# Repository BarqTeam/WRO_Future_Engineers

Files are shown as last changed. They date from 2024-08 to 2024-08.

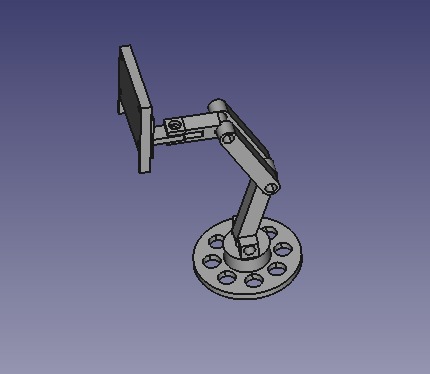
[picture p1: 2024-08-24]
models/camerastand/assembly_for_the_stand.jpeg

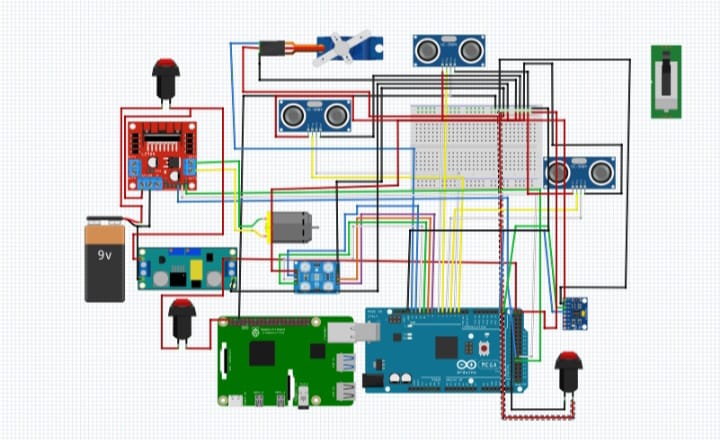
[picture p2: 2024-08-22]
schemes/Schematic_diagram.jpeg

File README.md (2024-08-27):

Engineering materials
====

This repository contains engineering materials of a self-driven vehicle's model participating in the WRO Future Engineers competition in the season 2022.

## Content

* `t-photos` contains 2 photos of the team (an official one and one funny photo with all team members)
* `v-photos` contains 6 photos of the vehicle (from every side, from top and bottom)
* `video` contains the video.md file with the link to a video where driving demonstration exists
* `schemes` contains one or several schematic diagrams in form of JPEG, PNG or PDF of the electromechanical components illustrating all the elements (electronic components and motors) used in the vehicle and how they connect to each other.
* `src` contains code of control software for all components which were programmed to participate in the competition
* `models` is for the files for models used by 3D printers, laser cutting machines and CNC machines to produce the vehicle elements. If there is nothing to add to this location, the directory can be removed.
* `other` is for other files which can be used to understand how to prepare the vehicle for the competition. It may include documentation how to connect to a SBC/SBM and upload files there, datasets, hardware specifications, communication protocols descriptions etc. If there is nothing to add to this location, the directory can be removed.

  ## READ.ME table of content

1. [Project Overview](#project-overview)

   1.1. [Team Management](#Team-Management)
   
   1.3. [Vehicle Strengths](#Vehicle-Strengths)  

2. [Programming Language ](programming-language)

3. [The First Chassis](#The-First-Chassis)

4. [Programming Challenges](#Programming-Challenges)

5. [Lap Counting Mechanism](#Lap-Counting-Mechanism)

6. [Obstacle Avoidance Round Challenge](#Obstacle-Avoidance-Round-Challenge)

7. [Power](#Power)

8. [components](#components)

9. [Future Work](#Future-Work)

## Introduction

Hello everyone,

We are the [Barq Engineers] from Palestine. We are a group of three ambitious young men: Amjad Ghannam, Rayan Farid, and Qusay Laila , with our car {BURAQ} represents not only our drive for technological advancement but also a symbol of hope and aspiration for the people of Palestine. Burag reflects the speed and brilliance of this legendary creature, embodying our ambition to overcome obstacles and make a mark on the world stage. Through Burag, we aim to demonstrate the remarkable achievements that Palestinian youth can accomplish, even in the face of adversity. .

In this competition, our goal is to showcase to the world what Palestinian youth can achieve, even under the harsh conditions of occupation. Through our efforts, we aim to send a powerful message about resilience, creativity, and the limitless potential that exists within every Palestinian boy.

## Project Overview

We began working on the WRO Future Engineers 2024 competition nearly three months ago. 
The WRO Future Engineers competition challenges teams to design and build autonomous vehicles capable of navigating complex paths and obstacles. Participants must integrate advanced engineering, programming, and design skills to create innovative solutions. The competition emphasizes creativity, technical precision, and teamwork, pushing the limits of robotics and AI. Teams showcase their work in a final competition, judged on performance, design, and innovation.

Our team, led by Qusay Laila, developed an advanced self-driving car from scratch, integrating CNC-machined and 3D-printed parts with components from the EV3 Lego kit. Powered by a 24-volt lithium battery, the car boasts high speed, smooth maneuverability, and excellent acceleration thanks to a well-designed differential and a gear ratio of 1.4:1. We included a Pi camera for obstacle detection and fine-tuned its software for optimal performance. We ensured the vehicle's seamless integration of mechanical and software systems. The car is lightweight at 1.2 kg, with room to compete in various challenges beyond the Future Engineers competition. Our GitHub repository documents the entire journey, including coding, design, and team management strategies.
You can find more details about the competition in the official rules.

## 1.1 Team Management

We are deeply grateful to everyone who contributed to our work. The success of this project is a testament to the dedication and collaboration of our incredible team, which consists of:

* Amjad Ghannam:
Amjad is responsible for managing our social media accounts, including GitHub. He is the creative force behind our design concepts, overseeing the development of the car's body, its mechanical systems, and other related components. Additionally, Amjad assists with coding.
`Contact Information:`
                    _ Email: amjadgh72@gmail.com
                    _ WhatsApp: +972594387565

* Qusay Laila:
Qusay is our team leader and the mastermind behind problem-solving. He excels in CAD design and manages the main code, assembling all the functions like pieces of a Lego set.
`Contact Information:`
                   _ Email: qusaylaila.work@gmail.com
                    _WhatsApp: +972592509054

* Rayan Farid:
Rayan is our designer for 3D parts and CNC components. He also manages serial communication and contributes to the code alongside Qusay. Additionally, Rayan serves as a GitHub editor.
`Contact Information:`
                    _ Email: rayanplaystation180@gmail.com
                     _WhatsApp: +972568997345

*The Coach: Eng. Mohammad Muamar
Eng. Mohammad Muamar, a Palestinian engineer and graduate of Palestine Polytechnic University in Hebron, has been our steadfast guide throughout this journey. His unwavering support, especially during challenging times, has been invaluable.
`Contact Information:`
Email: moh.mummar@gmail.com
Phone: +970594958003
Palestine Polytechnic University

We extend our heartfelt gratitude to our coach and all the team members who have played a crucial role in bringing this project to life.

## 1.2Barq team's social accounts
* youtube : https://www.youtube.com/@barqteam
* Instagram : https://www.youtube.com/redirect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
* you can also check our personal accounts in 1.1. [Team Management](#Team-Management)

## 1.3Vehicle Strengths
*  Chassis and Mechanism : Our vehicle was meticulously built from scratch, utilizing CNC-machined and 3D-printed parts. We also incorporated components from the EV3 Lego kit for critical mechanisms, such as the steering system and differential.

* Speed: Powered by a 24-volt lithium battery, our car achieves impressive speeds, giving it a competitive edge in performance.

* Mobility and Flexibility: The differential system significantly enhances the vehicle's ability to maneuver, providing smooth and flexible turns.

* Acceleration: The car boasts excellent acceleration, thanks to a well-calibrated gear ratio of 1.4:1 and a high-torque gear system that delivers powerful performance.

 ## 2. Programming Languages
We utilized C++ for coding the Arduino, ensuring efficient and reliable control of the hardware. Additionally, we employed Python to code the Raspberry Pi, particularly for implementing OpenCV with the Pi Camera.

## 3. The First Chassis
Initially, we decided to modify an RC car by adding the necessary components and creating a second layer to put them on. However, we encountered several challenges. The first issue arose when trying to create proper holes for mounting the servo motor. This led to further complications when attempting to implement a rack and pinion steering system (you can view the FreeCAD models for the rack and pinion in the "Models" section of this repository) using an MG699R servo motor.

Due to the high power and torque of the servo, it couldn't stay securely in place and kept shifting, which compromised the stability of the steering system. As a result, we decided to move on to our next plan: building a new chassis from scratch.

## 4. Programming Challenges
##Detecting Turns and Direction
In the WRO Future Engineers competition, the car's direction isn't fixed—it can move either clockwise or counterclockwise, adding complexity to navigation. This unpredictability is particularly challenging when the car needs to execute precise U-turns at specific points on the track.

### First Solution: Using the TCS3200 Color Sensor
* Color Detection: We initially programmed the TCS3200 sensor to identify specific colors on the track. An orange line signaled that the car should turn clockwise, while a blue line indicated a counterclockwise turn.

* Controlled Turning: Upon detecting a color, the car was instructed to turn at a specific angle. This angle was precisely controlled using an Inertial Measurement Unit (IMU), ensuring the car made accurate and consistent turns, regardless of external factors like speed or track conditions.

* Code Implementation: The process was automated through predefined functions such as detectOrangeLine and detectBlueLine, which triggered the appropriate turning actions based on the color detected.

This approach provided a straightforward method for determining the car's direction based on visual cues from the track, with the IMU ensuring precise turning control. However, this solution proved suboptimal due to the car's high speed and the limitations of the TCS3200, which was not the best choice for color detection in this context.

### Second Solution: Using Three Ultrasonic Sensors
* Direction Determination: We implemented three ultrasonic sensors to guide the car's movement based on real-time distance measurements. These sensors were strategically positioned to monitor distances on the left, right, and front of the car. When a turn was required, the direction was determined by comparing the distances detected by the sensors:

* If the right sensor measured a greater distance than the left sensor, the car would turn clockwise.
* Conversely, if the left sensor detected a greater distance, the car would turn counterclockwise.
#### Front Sensor Activation:
The front ultrasonic sensor played a critical role in detecting when the car was approximately 50 cm away from an obstacle or a turning point. This detection served as a trigger for the car to initiate the turn.

This approach emphasized spatial awareness and precise distance measurement, allowing the car to make informed directional decisions based on its environment rather than relying on visual cues. Ultimately, we decided that this solution was the most effective for our needs.

## 5.Lap Counting Mechanism:
#### Loop-Based Counting with Ultrasonic Sensor and IMU

##### Overview:
This method utilizes a software-based loop counter to track lap completion. The robot employs an ultrasonic sensor to detect when a lap is completed. If the sensor measures a distance of less than 50 cm to a specified point or object, the system registers the start of a new lap. The robot's steering is precisely managed by an Inertial Measurement Unit (IMU), ensuring accurate navigation during turns.

## IMU-Based Steering
#### Overview: 
In our autonomous vehicle, precise steering control is essential for accurate navigation. We achieve this through an IMU-based steering mechanism. The Inertial Measurement Unit (IMU) supplies real-time data on the vehicle’s angular velocity, which is crucial for calculating the yaw angle (the vehicle's turning angle) and ensuring stable and accurate steering.

#### Understanding the IMU:
An IMU (Inertial Measurement Unit) integrates several sensors, typically including a 3-axis accelerometer and a 3-axis gyroscope. These components work together to monitor the vehicle's movement and orientation in three-dimensional space.

* Accelerometer: Measures acceleration along the X, Y, and Z axes, which helps determine the vehicle’s tilt and linear movement.
* Gyroscope: Measures angular velocity (the rate of rotation) around the X, Y, and Z axes, providing critical information for understanding rotational motion, especially the yaw angle.
#### The X, Y, and Z Axes: 
Understanding these axes is fundamental for interpreting IMU data:

* X-Axis: Represents roll, the tilting motion of the vehicle from side to side.
* Y-Axis: Represents pitch, the tilting motion of the vehicle from front to back.
* Z-Axis: Represents yaw, the rotational movement around the vertical axis, crucial for steering as it defines the vehicle’s direction of travel.
#### Calculating the Yaw Angle: 
The yaw angle (
�
�
θ 
z

 ) quantifies the vehicle's rotation around the Z-axis. The IMU’s gyroscope provides angular velocity data along this axis, indicating the rate of rotation.

To determine the vehicle's heading, we calculate the yaw angle by integrating the angular velocity over time. This calculation updates continuously to maintain precise tracking of the vehicle’s direction.

The yaw angle is computed using the following equation:

\theta_z = \theta_{z, \text{previous}} + \left( \frac{\text{gyro}_z - \text{gyro_z_offset}}{131.0} \right) \times \Delta t

Where:

�
�
θ 
z

  is the current yaw angle.
�
�
,
previous
θ 
z,previous

  is the yaw angle from the previous time step.
gyro
�
gyro 
z

  is the angular velocity around the Z-axis, provided by the gyroscope.
\text{gyro_z_offset} is the gyroscope offset, determined during calibration to correct for any drift.
Δ
�
Δt is the time elapsed between the current and previous readings.
### Importance of Gyro Offset:
The gyroscope offset (\text{gyro_z_offset}) is vital as gyroscopes can experience slight errors or biases over time, known as drift. By calculating and subtracting this offset, we ensure that the yaw angle calculation remains accurate, preventing gradual deviations from the true value.

## 6. Obstacle Avoidance Round Challenge
In this round, we integrated the Pi camera to enable the car to navigate between obstacles more efficiently. We started by developing the optimal code to achieve the best resolution and frame rate, while also fine-tuning color filters to ensure precise detection of red and green obstacles. This setup allows the car to identify and respond to obstacles accurately, minimizing the risk of errors. 
Here, you can see the code we developed to optimize the color filters, ensuring the highest accuracy in obstacle detection. This code is tailored to deliver the best possible resolution and frame rate, allowing our car to efficiently identify and respond to red and green obstacles with minimal errors.

cpp
import picamera
import cv2
import numpy as np
import serial
from picamera.array import PiRGBArray
import time

#Initialize serial communication with Arduino
arduino = serial.Serial('/dev/ttyACM0', 115200)  # Replace with your actual port

#Initialize Picamera
camera = picamera.PiCamera()
camera.resolution = (500, 200)  # Lower the resolution for faster processing
camera.framerate = 60  # Increase the frame rate
camera.brightness = 50  # Increase brightness by approximately 50%
raw_capture = PiRGBArray(camera, size=(500, 200))

#Allow the camera to warm up
time.sleep(0.1)

def format_data(object_type, x, y, width, height):
    """Format data as a string."""
    return f"{object_type}{x:05}{y:05}{width:05}{height:05}\n"

def get_largest_contour(mask, min_area=500):
    """Find the largest contour in the given mask, ignoring small contours."""
    contours, _ = cv2.findContours(mask, cv2.RETR_TREE, cv2.CHAIN_APPROX_SIMPLE)
    filtered_contours = [c for c in contours if cv2.contourArea(c) > min_area]
    if filtered_contours:
        largest_contour = max(filtered_contours, key=cv2.contourArea)
        return largest_contour
    return None

try:
    for frame in camera.capture_continuous(raw_capture, format="bgr", use_video_port=True):
        imageFrame = frame.array

        # Increase contrast
        contrast_factor = 1.5  # Adjust this value to increase contrast
        imageFrame = cv2.convertScaleAbs(imageFrame, alpha=contrast_factor, beta=0)

        # Convert BGR image to HSV
        hsvFrame = cv2.cvtColor(imageFrame, cv2.COLOR_BGR2HSV)

        # Increase saturation and brightness to make colors more vivid
        hsvFrame[:, :, 1] = cv2.add(hsvFrame[:, :, 1], 30)
        hsvFrame[:, :, 2] = cv2.add(hsvFrame[:, :, 2], 30)

        # Define color ranges
        red_lower1 = np.array([0, 140, 140], np.uint8)
        red_upper1 = np.array([10, 255, 255], np.uint8)
        red_lower2 = np.array([160, 140, 140], np.uint8)
        red_upper2 = np.array([180, 255, 255], np.uint8)

        green_lower = np.array([35, 100, 100], np.uint8)
        green_upper = np.array([85, 255, 255], np.uint8)

        # Create masks for red and green colors
        red_mask1 = cv2.inRange(hsvFrame, red_lower1, red_upper1)
        red_mask2 = cv2.inRange(hsvFrame, red_lower2, red_upper2)
        red_mask = cv2.bitwise_or(red_mask1, red_mask2)

        green_mask = cv2.inRange(hsvFrame, green_lower, green_upper)

        # Apply additional thresholding to refine masks
        kernel = np.ones((7, 7), "uint8")  # Slightly larger kernel size
        red_mask = cv2.dilate(red_mask, kernel)
        red_mask = cv2.erode(red_mask, kernel)

        green_mask = cv2.dilate(green_mask, kernel)
        green_mask = cv2.erode(green_mask, kernel)

        # Find the largest red and green objects
        largest_red_contour = get_largest_contour(red_mask)
        largest_green_contour = get_largest_contour(green_mask)

        # Process the largest red object
        if largest_red_contour is not None:
            rect = cv2.minAreaRect(largest_red_contour)
            box = cv2.boxPoints(rect)
            box = np.int0(box)
            imageFrame = cv2.drawContours(imageFrame, [box], 0, (0, 0, 255), 2)
            
            width = int(abs(rect[1][0]))
            height = int(abs(rect[1][1]))
            
            # Calculate the center X position
            x_center = int((box[0][0] + box[2][0]) / 2)
            y_center = int(rect[0][1])
            
            data_red = format_data(1, x_center, y_center, width, height)
            arduino.write(data_red.encode())
            print(data_red)
        # Process the largest green object
        if largest_green_contour is not None:
            rect = cv2.minAreaRect(largest_green_contour)
            box = cv2.boxPoints(rect)
            box = np.int0(box)
            imageFrame = cv2.drawContours(imageFrame, [box], 0, (0, 255, 0), 2)
            
            width = int(abs(rect[1][0]))
            height = int(abs(rect[1][1]))
            
            # Calculate the center X position
            x_center = int((box[0][0] + box[2][0]) / 2)
            y_center = int(rect[0][1])
            
            data_green = format_data(2, x_center, y_center, width, height)
            arduino.write(data_green.encode())
            print("green")
            print(data_green)
        # Display the result
        cv2.imshow("colors", imageFrame)
        
        # Clear the stream for the next frame
        raw_capture.truncate(0)

        # Add a delay and check for 'q' key press
        if cv2.waitKey(1) & 0xFF == ord('q'):
            break

finally:
    # Close serial connection and camera when done
    arduino.close()
    camera.close()
    cv2.destroyAllWindows()

## 7.Power 
Lithium Polymer (LiPo) batteries are highly favored in robotics due to their superior energy density, lightweight construction, and capability to deliver high currents. These attributes make them exceptionally suited for applications that demand both substantial power and agility, such as our autonomous robot.
Advantages of LiPo Batteries:

1- High Energy Density:

2- High Discharge Rate:

3- Lightweight and Compact:

4- Stable Voltage Output:

### Why a 24V Battery?
#### Voltage Compatibility:

The 24V output is ideal for many high-power robotics components, such as motors and motor drivers, which are designed to operate efficiently at this higher voltage. This reduces the need for additional voltage conversion and simplifies the power distribution system, making it more efficient for demanding applications.

#### Power Sufficiency:

A 24V battery provides ample power for the entire robot, ensuring that high-demand components like motors receive sufficient voltage for optimal performance. This higher voltage allows for efficient voltage regulation to lower voltages (e.g., 5V or 3.3V) for other electronics, while maintaining overall power efficiency.

Key Characteristics of the 24V LiPo Battery:

* Voltage: 24V nominal, ideal for direct use with high-power motors and for stepping down to lower voltages.
* Capacity: Typically ranges from 2000mAh to 6000mAh, influencing how long the robot can operate before requiring a recharge.
* Discharge Rate: High C-ratings (e.g., 20C) ensure the battery can deliver the necessary current for motors and other components during peak usage.
* Weight: Lightweight design, generally around 300g for a 2200mAh battery, important for maintaining the robot’s agility and maneuverability.

  ## 8.components
| Quantity | Status | Description |
| ---| --- | ---|
| 1 | Raspberry Pi 4 Model B |https://www.raspberrypi.com/products/raspberry-pi-4-model-b/ |
| 1 | *Arduino Mega: | (https://store.arduino.cc/products/arduino-mega-2560-rev3) |
| 1 | The L298N Motor Driver: | https://components101.com/modules/l293n-motor-driver-module |
| 1 | Servo motor MG996r |https://www.jsumo.com/mg996r-servo-motor-digital |
| 1 | pi camera module 2| https://www.raspberrypi.com/products/camera-module-v2/ |
| 1 | MPU-9250 |https://learn.sparkfun.com/tutorials/mpu-9250-hookup-guide/all |
| 3 | *HC-SR04 Ultrasonic Sensor  | https://www.sparkfun.com/products/15569 |
|1 | lithum Battery 24v | "We have connected two 12-volt batteries in series using a 6S Battery Management System (BMS) to ensure balanced charging and efficient power management." |
|1 | HW-083 | https://www.elektormagazine.com/labs/hw-083-hack-evolution-charger |

## 9.Future Work
Our car is versatile enough to compete in multiple competitions beyond the Future Engineers competition. Its high speed, lightweight design, and exceptional flexibility in turning—thanks to the differential gear system—make it a strong contender. Additionally, the precise steering system enhances its maneuverability, allowing it to perform with accuracy and agility across various challenges.

## How to prepare the repo based on the template

_Remove this section before the first commit to the repository_

1. Clone this repo by using the `git clone` functionality.
2. Remove `.git` directory
3. [Initialize a new public repository on GitHub](https://github.com/new) by following instructions from "create a new repository on the command line" section (appeared after pressing "Create repository" button).

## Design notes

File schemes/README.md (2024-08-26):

Electromechanical diagrams
====
This section details all the components utilized in the project, accompanied by a schematic diagram illustrating how they are interconnected.

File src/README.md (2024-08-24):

Control software
====

In this repository, we have uploaded various code versions that document each stage of our development process. Each file is named for easy reference, allowing you to efficiently track progress and identify the final, most optimized version.

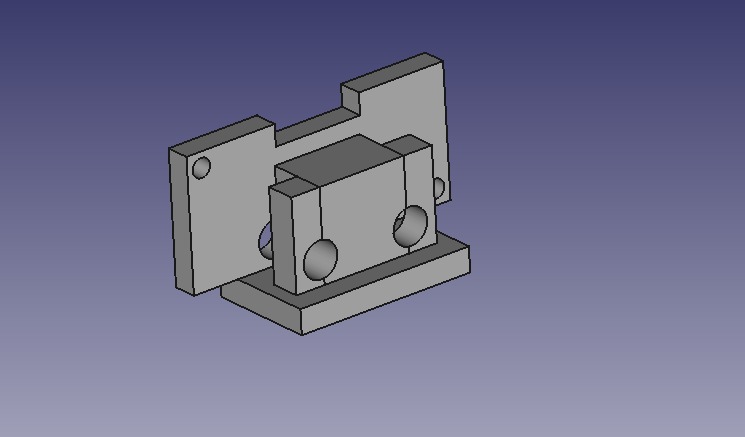
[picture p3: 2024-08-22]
models/ultrasonic_right+left.jpeg

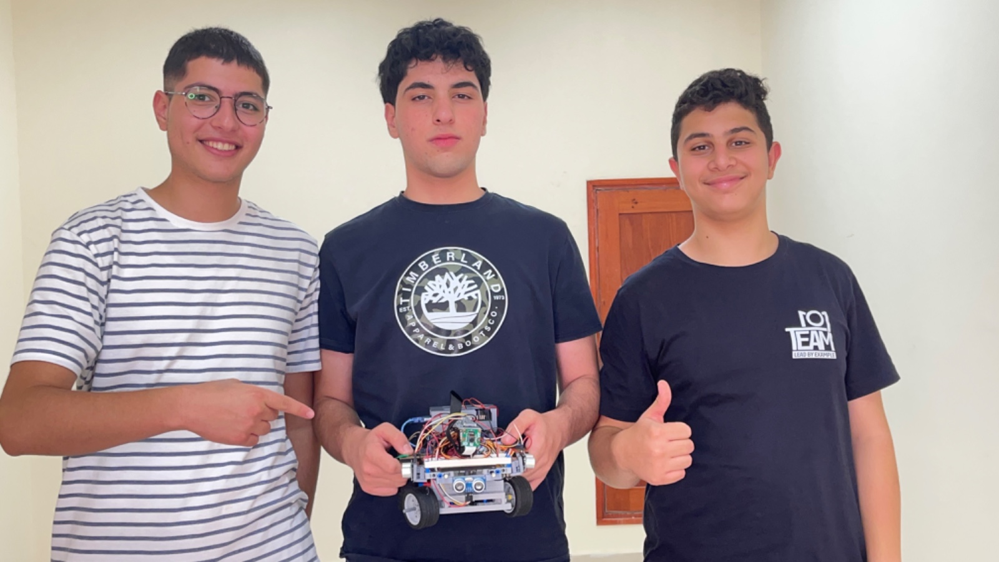
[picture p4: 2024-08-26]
t-photos/teamphotowithcar.jpeg

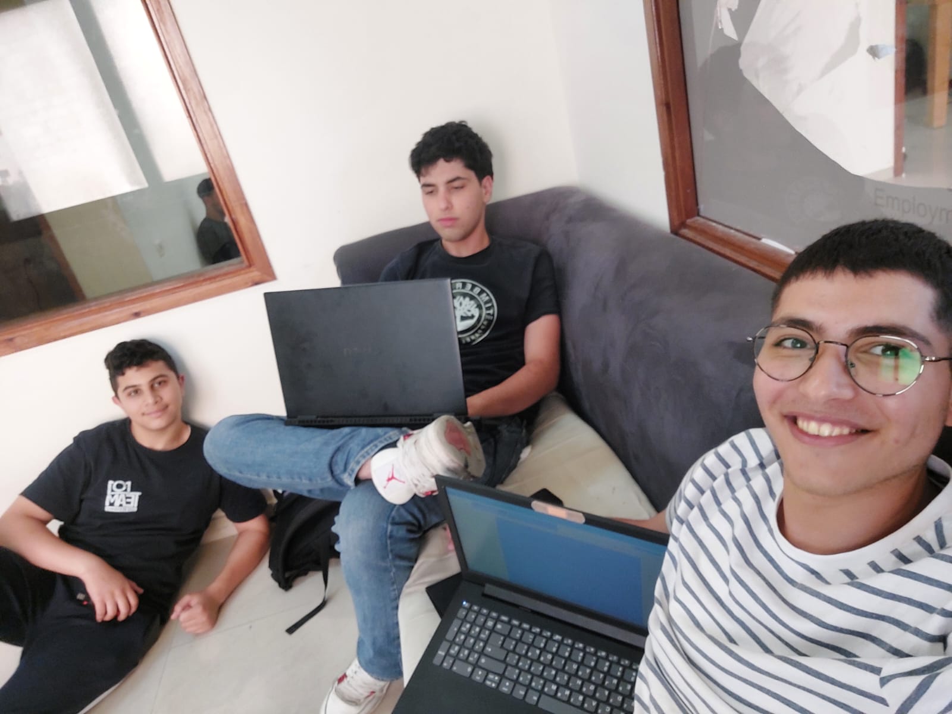
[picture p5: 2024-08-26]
t-photos/Funnyphoto.jpeg

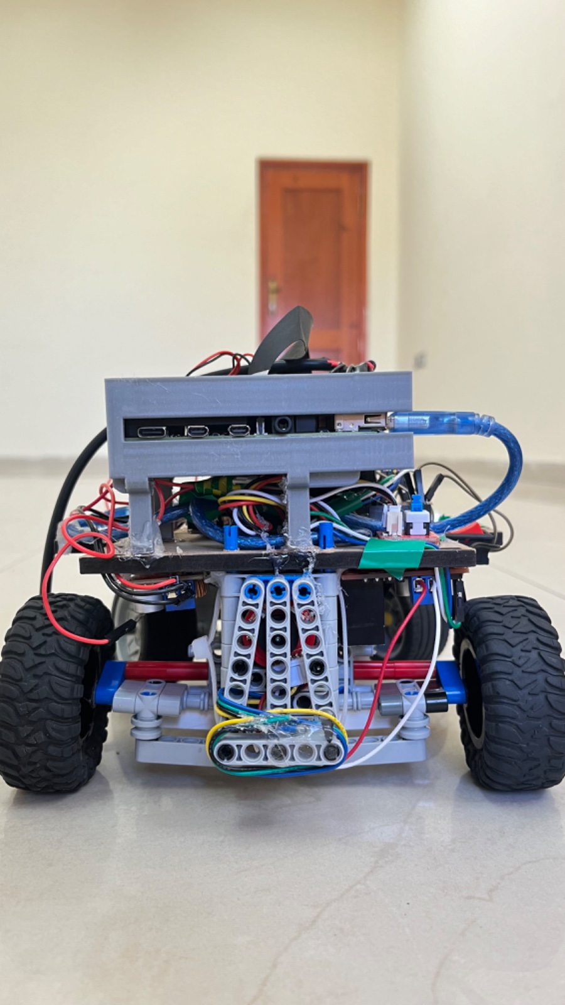
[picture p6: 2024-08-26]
v-photos/Back.jpeg

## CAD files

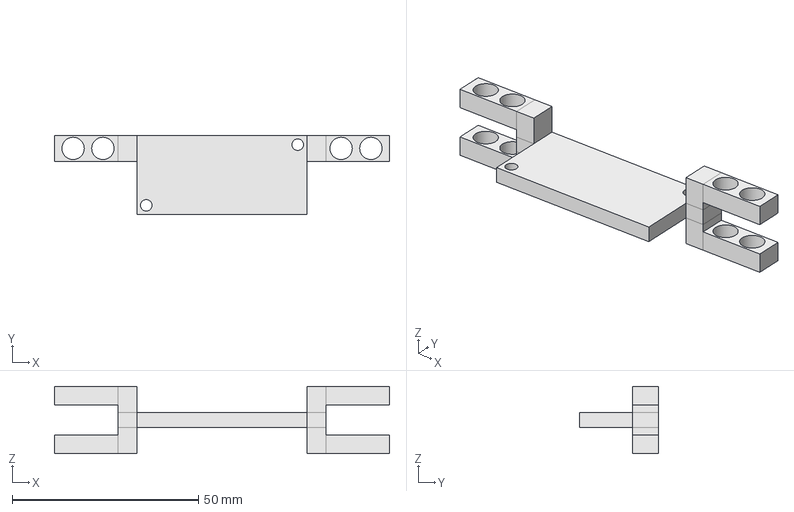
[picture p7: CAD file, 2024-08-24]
models/freecad_WRO/ultrasonic_forward.FCStd
90.0 x 21.3 x 18.0 mm

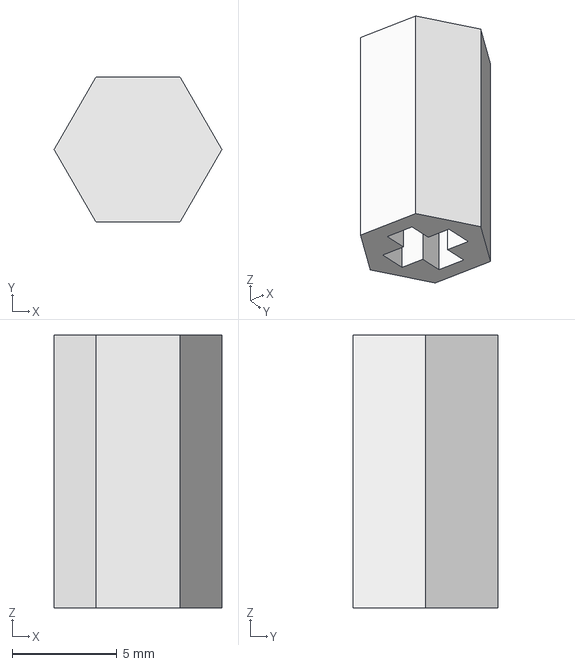
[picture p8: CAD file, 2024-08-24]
models/freecad_WRO/wheels_joint.FCStd
7.99 x 6.92 x 13.0 mm

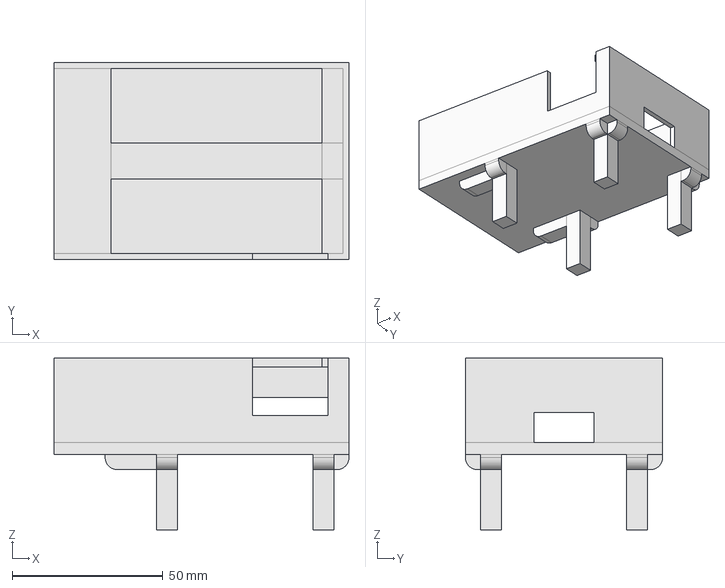
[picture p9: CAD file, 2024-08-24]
models/freecad_WRO/raspberrypi_sheild.FCStd
98.0 x 65.5 x 57.0 mm

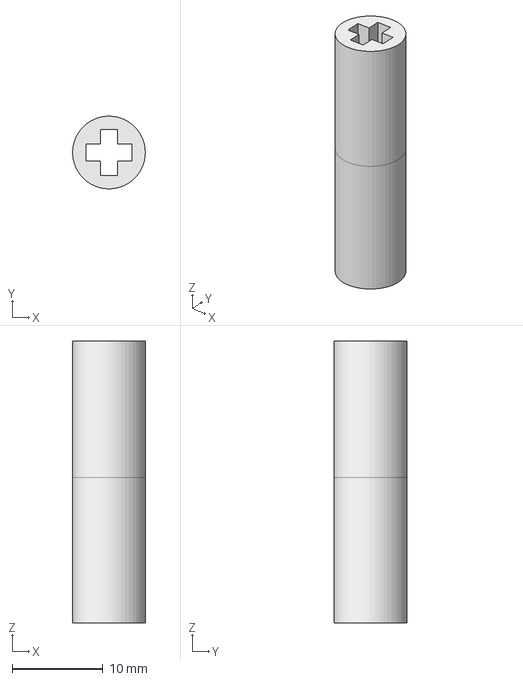
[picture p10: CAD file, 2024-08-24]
models/freecad_WRO/servo_plugin.FCStd
7.99 x 8.00 x 31.0 mm

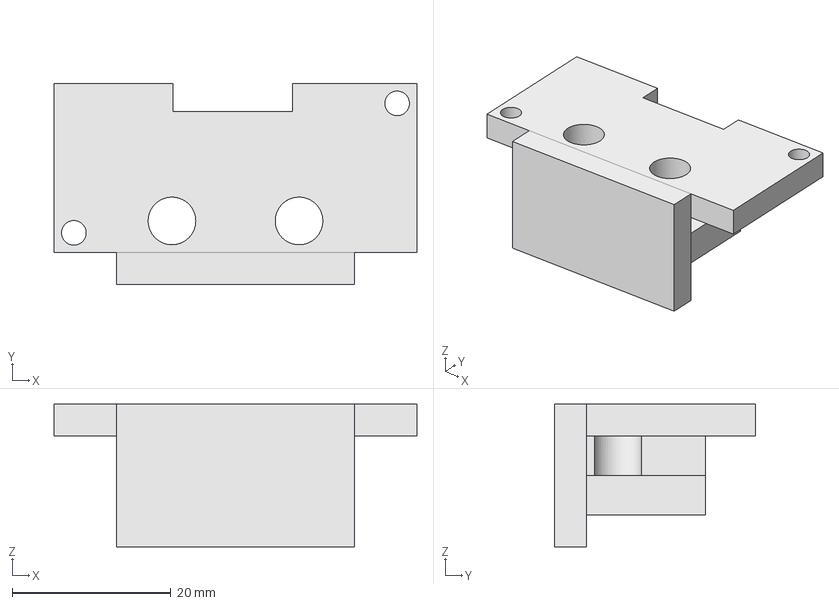
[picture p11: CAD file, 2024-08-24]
models/freecad_WRO/ultrasonic_right+left.FCStd
45.7 x 25.3 x 18.0 mm

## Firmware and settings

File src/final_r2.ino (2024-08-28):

#include <Wire.h>
#include <MPU6050.h>
#include <Servo.h>

// Pin Definitions
#define SERVO_PIN 13
#define BUTTON_PIN 22
#define IN3 42
#define IN4 43
#define ENB 5
#define INITIAL_ANGLE 99
#define trigPinl 2
#define echoPinl 3
#define trigPinr 11
#define echoPinr 10
#define trigPinf 6
#define echoPinf 7

MPU6050 mpu;
Servo myServo;
int16_t gz;
long previous_time;
float yaw_angle = 0;
float gyro_z_offset = 0;
int calibration_count = 1000; // Number of samples for calibration
int currentAngle = INITIAL_ANGLE;
unsigned long lastTime = 0;
int i = 0; // Declare variable 'i'
int targetYawAngle = 0;
float ANGLE_CORRECTION_FACTOR = 1;

// PID variables
float Kp = 1.0; // Proportional gain
float Ki = 0.0; // Integral gain
float Kd = 0.0; // Derivative gain
float previousError = 0;
float integral = 0;
float input = 0;
int return_front = 0;
int return_right = 0;
int return_left = 0;
int section = 0;
int counter = 0;
int place = 0;
int fixing_time = 0;
int turn = 0;
int first_time = 0;
int turning_counter = 0;

// Function declarations
void calculateGyroDrift();
void MoveFWwithGyro();
void MoveFWwithGyro_Reverse();
int usForward();
int usRight();
int usLeft();
void stopMotor();
void stopfromcrashing_andreturn();

void setup() {
    // Serial.begin(250000);
    Wire.begin();
    mpu.initialize();
    pinMode(IN3, OUTPUT);
    pinMode(IN4, OUTPUT);
    pinMode(ENB, OUTPUT);
    pinMode(BUTTON_PIN, INPUT);

    // Ultrasonic sensor setup
    pinMode(trigPinl, OUTPUT);
    pinMode(echoPinl, INPUT);
    pinMode(trigPinr, OUTPUT);
    pinMode(echoPinr, INPUT);
    pinMode(trigPinf, OUTPUT);
    pinMode(echoPinf, INPUT);

    // Check if MPU6050 is connected properly
    // Serial.println(mpu.testConnection() ? "MPU6050 connected" : "MPU6050 connection failed");

    // Calibrate the gyro to calculate drift
    // Serial.println("Calibrating gyro...");
    calculateGyroDrift();
    // Serial.print("Gyro Z Offset: ");
    // Serial.println(gyro_z_offset);

    // Servo setup
    myServo.attach(SERVO_PIN);
    // Serial.print("Initial angle set to: ");
    // Serial.println(currentAngle);
    myServo.write(INITIAL_ANGLE);

    // Motor setup
    digitalWrite(IN3, HIGH);  // Set direction
    digitalWrite(IN4, LOW);   // Set direction
    analogWrite(ENB, 0);      // Set initial speed (0-255)

    previous_time = millis(); // Record the start time

    while (digitalRead(BUTTON_PIN) == LOW) {
        // Serial.println(usLeft());
    }

    return_front = usForward();
    return_right = usRight();
    return_left = usLeft();

    analogWrite(ENB, 210);

    while (usForward() > 60) {
        MoveFWwithGyro();
        // stopfromcrashing_andreturn();
    }

    if (usLeft() > usRight() ) {
        i = 1;
    } else if (usLeft() < usRight() ) {
        i = 2;
    } else {
        while (1) {}
    }
    

    while ( counter <= 11){
      Green_Turn();
      Red_Turn();
      // Serial.print(counter , ENB);
      // Serial.print("\n");
      while (i == 1 && counter <= 11 ) {
        Green_Turn();
        Red_Turn();
        // Serial.print(counter);
        // Serial.print("\n");
        MoveFWwithGyro();
        if (usForward() < 50 && usLeft() > 70) {
          targetYawAngle += 90;
          counter += 1;
          while (turning_counter < 1000) {
            MoveFWwithGyro();
            // Serial.print(counter);
            // Serial.print("\n");
            turning_counter += 1;
          }
          turning_counter = 0;

        }
      }
  
      while (i == 2 && counter <= 11) {
        Green_Turn();
        Red_Turn();
        // Serial.print(counter);
        // Serial.print("\n");
        MoveFWwithGyro();
        // Serial.print(counter);
        // Serial.print("\n");
        if (usForward() < 50 && usRight() > 70) {
          // Serial.print(counter);
          // Serial.print("\n");
          targetYawAngle -= 90;
          counter += 1;
          while (turning_counter < 1000) {
            // Serial.print(counter);
            // Serial.print("\n");
            MoveFWwithGyro();
            turning_counter += 1;
          }
          turning_counter = 0;
        }
      }
    }
    analogWrite(ENB, 0);
    while (usForward() > 140) {
        // Serial.print(counter);
        // Serial.print("\n");
        MoveFWwithGyro();
        
        // stopfromcrashing_andreturn();
    }
    while (usForward() < 140){

  
    stopMotor();
    // Serial.print("nigga");
    // Serial.print("\n");
    }
}
    

void loop() {
   
}

// Function Definitions

void MoveFWwithGyro() {
  long current_time = millis();
  float elapsed_time = (current_time - previous_time) / 1000.0; // Calculate elapsed time in seconds
  previous_time = current_time;

  // Get Z-axis rotation value
  gz = mpu.getRotationZ();

  // Apply drift correction
  gz -= gyro_z_offset;

  // Convert gyroscope reading to degrees per second
  float gyro_z = (gz / 131.0) + 0.004354;

  // Calculate the yaw angle by integrating the angular velocity over time
  yaw_angle += gyro_z * elapsed_time;

  // Apply the angle correction factor and constrain the servo angle
  float angleError = (yaw_angle - targetYawAngle) * ANGLE_CORRECTION_FACTOR;
  float t = angleError + INITIAL_ANGLE;
  t = constrain(t, 70, 130); // Keep the angle within bounds
  myServo.write(int(t));

  // Debugging information
  // Serial.print("Yaw Angle: "); Serial.println(yaw_angle);
  // Serial.print("Target Yaw Angle: "); Serial.println(targetYawAngle);
  // Serial.print("Servo Angle: "); Serial.println(t);
}

void calculateGyroDrift() {
  gyro_z_offset = 0; // Reset the offset
  long temp_offset = 0; // Temporary variable to store the sum
  int validReadings = 0;

  for (int i = 0; i < calibration_count; i++) {
    gz = mpu.getRotationZ();

    // Exclude any extreme outliers
    if (gz > -32760 && gz < 32760) {
      temp_offset += gz;
      validReadings++;
    }

    delay(3); // Short delay between readings to stabilize
  }

  // Average the valid readings to get the drift (offset) value
  if (validReadings > 0) {
    gyro_z_offset = temp_offset / validReadings;
  }
}

void MoveFWwithGyro_Reverse() {
  long current_time = millis();
  float elapsed_time = (current_time - previous_time) / 1000.0; // Calculate elapsed time in seconds
  previous_time = current_time;

  // Get Z-axis rotation value
  gz = mpu.getRotationZ();

  // Apply drift correction
  gz -= gyro_z_offset;

  // Convert gyroscope reading to degrees per second
  float gyro_z = (gz / 131.0) + 0.001517;

  // Calculate the yaw angle by integrating the angular velocity over time
  yaw_angle += gyro_z * elapsed_time;

  // Apply the angle correction factor, invert the direction, and constrain the servo angle
  float angleError = (targetYawAngle - yaw_angle) * ANGLE_CORRECTION_FACTOR; // Invert the angle calculation
  float t = angleError + INITIAL_ANGLE;
  t = constrain(t, 60, 140); // Keep the angle within bounds
  myServo.write(int(t));

  // Debugging information
  // Serial.print("Yaw Angle: "); Serial.println(yaw_angle);
  // Serial.print("Target Yaw Angle: "); Serial.println(targetYawAngle);
  // Serial.print("Servo Angle: "); Serial.println(t);
}


int usLeft() {
    digitalWrite(trigPinl, LOW);
    delayMicroseconds(2);
    digitalWrite(trigPinl, HIGH);
    delayMicroseconds(10);
    digitalWrite(trigPinl, LOW);
    long duration = pulseIn(echoPinl, HIGH, 30000); // Timeout after 30ms
    if (duration == 0) return 200; // If no echo, return a large distance
    return duration * 0.034 / 2;
}

int usRight() {
    digitalWrite(trigPinr, LOW);
    delayMicroseconds(2);
    digitalWrite(trigPinr, HIGH);
    delayMicroseconds(10);
    digitalWrite(trigPinr, LOW);
    long duration = pulseIn(echoPinr, HIGH, 30000); // Timeout after 30ms
    if (duration == 0) return 200; // If no echo, return a large distance
    return duration * 0.034 / 2;
}

int usForward() {
    digitalWrite(trigPinf, LOW);
    delayMicroseconds(2);
    digitalWrite(trigPinf, HIGH);
    delayMicroseconds(10);
    digitalWrite(trigPinf, LOW);
    long duration = pulseIn(echoPinf, HIGH, 30000); // Timeout after 30ms
    if (duration == 0) return 200; // If no echo, return a large distance
    return duration * 0.034 / 2;
}

void stopMotor() {
    analogWrite(ENB, 0);
}

void stopfromcrashing_andreturn() {
    if (usForward() < 10) {
        analogWrite(ENB, 0);
        delay(100);
        digitalWrite(IN3, LOW);  
        digitalWrite(IN4, HIGH);
        analogWrite(ENB, 210);
        while (fixing_time < 300) {
            fixing_time += 1;
            MoveFWwithGyro_Reverse();
        }
        analogWrite(ENB, 0);
        delay(100);
        digitalWrite(IN3, HIGH);  
        digitalWrite(IN4, LOW);
        analogWrite(ENB, 210);
        fixing_time = 0;
    }
}
void Green_Turn() {
  while (GREEN()) {
    if (green_x() >= 640) {
      MoveFWwithGyro();
    }
    if (green_x() <= 640) {
      if (green_size() > 10000) { 
        targetYawAngle -= 30;
        // setpoint = targetYawAngle; // Update PID setpoint
        while (turning_counter < 80) {
          turning_counter += 1;
          MoveFWwithGyro();
        }
        targetYawAngle += 30;
        // setpoint = targetYawAngle; // Reset PID setpoint
        turning_counter = 0;
      }
    }
  }
}
void Red_Turn() {
  while (RED) {
    if (red_x() <= 500) {
      MoveFWwithGyro();
    }
    if (red_x() >= 500) {
      if (green_size() > 10000) { 
        targetYawAngle += 30;
        // setpoint = targetYawAngle; // Update PID setpoint
        while (turning_counter < 80) {
          turning_counter += 1;
          MoveFWwithGyro();
        }
        targetYawAngle -= 30;
        // setpoint = targetYawAngle; // Reset PID setpoint
        turning_counter = 0;
      }
    }
  }
}
bool RED() {
  if (Serial.available()) {
    String receivedData = Serial.readStringUntil('\n');
    
    if (receivedData.length() == 21) {
      int objectType = receivedData.charAt(0) - '0';
      if (objectType == 1) {
        int xPos = receivedData.substring(1, 6).toInt();
        int yPos = receivedData.substring(6, 11).toInt();
        int width = receivedData.substring(11, 16).toInt();
        int height = receivedData.substring(16, 21).toInt();
        
        // Serial.print("Received Data: ");
        // Serial.print("Type: ");
        // Serial.print(objectType);
        // Serial.print(", X: ");
        // Serial.print(xPos);
        // Serial.print(", Y: ");
        // Serial.print(yPos);
        // Serial.print(", Width: ");
        // Serial.print(width);
        // Serial.print(", Height: ");
        // Serial.println(height);

        return true;
      }
    }
  }
  return false;
}

// Function to handle GREEN object detection (type 2)
bool GREEN() {
  if (Serial.available()) {
    String receivedData = Serial.readStringUntil('\n');
    
    if (receivedData.length() == 21) {
      int objectType = receivedData.charAt(0) - '0';
      if (objectType == 2) {
        int xPos = receivedData.substring(1, 6).toInt();
        int yPos = receivedData.substring(6, 11).toInt();
        int width = receivedData.substring(11, 16).toInt();
        int height = receivedData.substring(16, 21).toInt();
        
        // Serial.print("Received Data: ");
        // Serial.print("Type: ");
        // Serial.print(objectType);
        // Serial.print(", X: ");
        // Serial.print(xPos);
        // Serial.print(", Y: ");
        // Serial.print(yPos);
        // Serial.print(", Width: ");
        // Serial.print(width);
        // Serial.print(", Height: ");
        // Serial.println(height);

        return true;
      }
    }
  }
  return false;
}

// Function to get the X value for a RED object (type 1)
int red_x() {
  if (RED()) {
    String receivedData = Serial.readStringUntil('\n');
    return receivedData.substring(1, 6).toInt();
  }
  return -1; // Return -1 if no RED object is detected
}

// Function to get the X value for a GREEN object (type 2)
int green_x() {
  if (GREEN()) {
    String receivedData = Serial.readStringUntil('\n');
    return receivedData.substring(1, 6).toInt();
  }
  return -1; // Return -1 if no GREEN object is detected
}

// Function to calculate the size (width * height) for a RED object (type 1)
int red_size() {
  if (RED()) {
    String receivedData = Serial.readStringUntil('\n');
    int width = receivedData.substring(11, 16).toInt();
    int height = receivedData.substring(16, 21).toInt();
    return width * height;
  }
  return -1; // Return -1 if no RED object is detected
}

// Function to calculate the size (width * height) for a GREEN object (type 2)
int green_size() {
  if (GREEN()) {
    String receivedData = Serial.readStringUntil('\n');
    int width = receivedData.substring(11, 16).toInt();
    int height = receivedData.substring(16, 21).toInt();
    return width * height;
  }
  return -1; // Return -1 if no GREEN object is detected
}
